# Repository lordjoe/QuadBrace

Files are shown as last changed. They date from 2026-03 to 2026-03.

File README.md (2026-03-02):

# QuadBrace — 3D-Printable Assistive Tool Holder for Quadriplegics

A set of parametric OpenSCAD models that together form a wrist-worn assistive device, allowing individuals with quadriplegia (tetraplegia) to independently pick up and use everyday tools such as forks, knives, and other utensils.

## Preview

| Wrist Brace | Main Box | Top Plate |
|:---:|:---:|:---:|
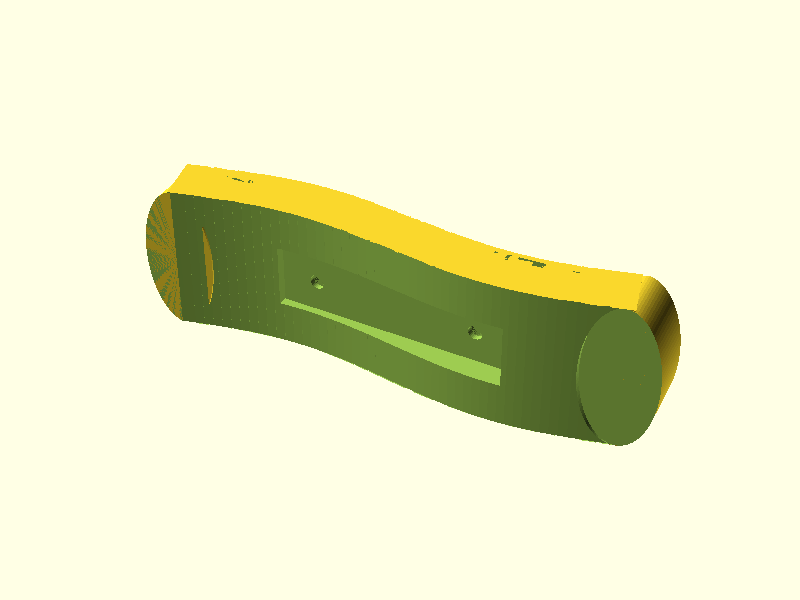
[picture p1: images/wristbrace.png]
Wrist Brace
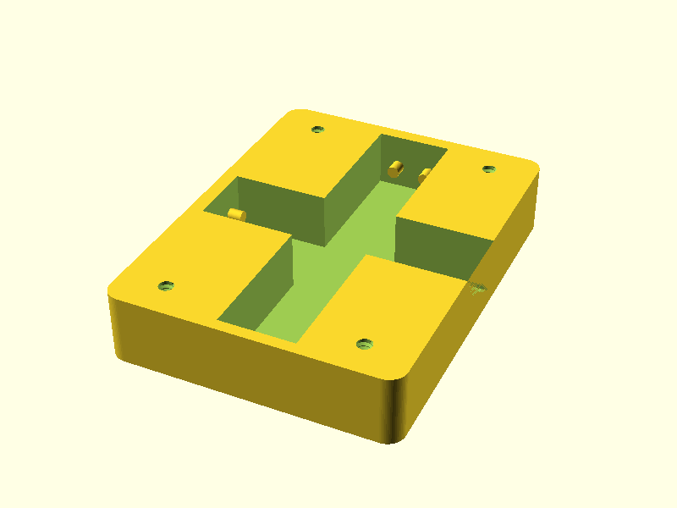
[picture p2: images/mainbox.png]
Main Box
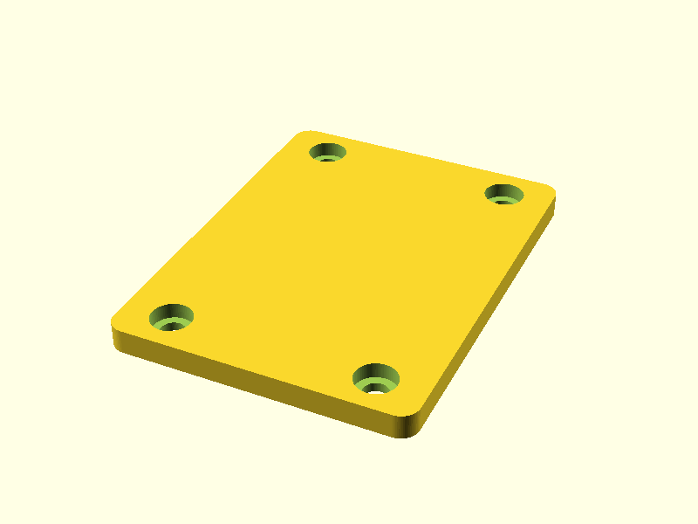
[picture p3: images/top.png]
Top Plate
|  |  |  |
| **Assembly — sliders and springs** — semi-transparent box; blue = Y-groove slider (wide end toward sealed wall), green = X-groove spring slider (at closed end), red/orange coils = springs from slider pegs to end-wall pegs |||
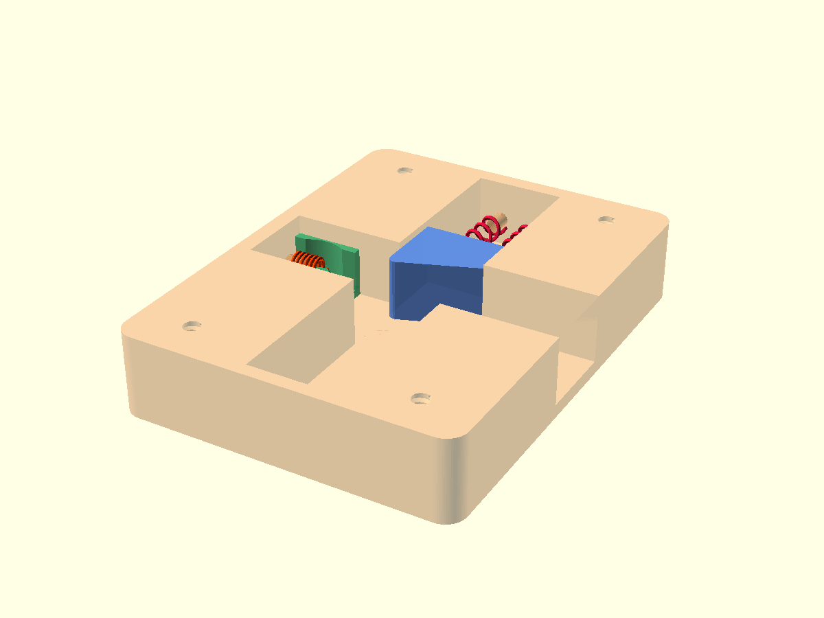
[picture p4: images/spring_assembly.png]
Spring assembly
|  |||

## Purpose

People living with quadriplegia often have limited or no hand/finger function, making it difficult or impossible to grip tools unaided. This device provides a spring-loaded, quick-release mounting system that attaches to the wrist and holds tools securely while allowing easy release — restoring a degree of independence for feeding and other daily tasks.

## How It Works

The assembly consists of four main functional layers:

1. **Wrist Brace** (`wristbrace.scad`) — A curved, sine-wave-contoured band that conforms to the wrist. Strap slots allow it to be secured with hook-and-loop (Velcro) straps. A rectangular cutout in the brace receives the Main Box.

2. **Main Box** (`MainBox.scad` + `Top.scad`) — A compact rectangular housing that mounts into the brace. It contains two orthogonal sliding grooves (one along the wrist, one across it) with spring pegs at each sealed end. A thin top plate caps the assembly.

3. **Slider / Pusher** (`Slider.scad`, `TopSpringSlider.scad`, `pusher2.scad`) — A slider block sits inside the groove and is held in place by spring pegs. Pressing a pusher lever releases the slider, which then carries the tool holder outward for easy access, then snaps back when released.

4. **Tool Holder** (`holder.scad`) — A cylindrical clamp that grips the shaft of a fork, knife, spoon, or similar tool. Slotted for quick swap of tools; tightened with a single screw. A matching **rest/cradle** (`fork_rest`) provides a surface to park the tool when the brace is removed.

## Files

| File | Description |
|---|---|
| `common_params.scad` | Shared dimensions and fit parameters for the Main Box assembly |
| `params_quadbrace.scad` | Shared parameters for the pusher, sleeve, slider, and wrist brace |
| `geom_helpers.scad` | Reusable geometry modules (rounded prisms, screw holes, spring pegs) |
| `MainBox.scad` | Main mounting box with cross-shaped grooves and spring pegs |
| `Top.scad` | Thin top plate with counterbored screw holes |
| `wristbrace.scad` | Sine-contoured wrist band with strap cutouts and box slot |
| `holder.scad` | Cylindrical tool clamp + flat rest/cradle |
| `pusher2.scad` | Pusher stem, shell sleeve, and end-cap release mechanism |
| `Slider.scad` | Slider block that travels in the Main Box grooves |
| `TopSpringSlider.scad` | Spring-loaded top slider variant |
| `pyramid.scad` | Pyramid/ramp geometry for slider leading edge |
| `key.scad` | Anti-rotation key geometry |
| `PrintAll.scad` | Print any combination of parts on one bed; set `print_all = true` or flip individual flags |
| `AssemblyPreview.scad` | Exploded assembly preview (all parts together) |

## Requirements

- [OpenSCAD](https://openscad.org/) 2021.01 or later
- [BOSL2 library](https://github.com/BelfrySCAD/BOSL2) — place the `BOSL2/` folder in your OpenSCAD library path

## Printing

All parts are designed for FDM printing (PLA or PETG recommended). No supports are required for most parts. Suggested settings:

- Layer height: 0.2 mm
- Infill: 30–40%
- Perimeters: 3+
- Hardware: M3 or #6/#8 machine screws (see parameter files for exact sizes)

## Customisation

All critical dimensions are centralised in `common_params.scad` and `params_quadbrace.scad`. Adjust wrist width, tool diameter, groove clearances, and peg sizes to match the user's anatomy and chosen hardware before slicing.

## License

Released under the [Creative Commons Attribution 4.0 International (CC BY 4.0)](https://creativecommons.org/licenses/by/4.0/) licence. You are free to print, modify, and share this design — attribution appreciated.

## Contributing

Pull requests and issue reports are welcome. If you adapt this design for a specific tool or user need, please share your fork so others can benefit.

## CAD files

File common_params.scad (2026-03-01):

include <BOSL2/std.scad>;
include <BOSL2/threading.scad>;
include <BOSL2/screws.scad>;
// common_params.scad
// Extracted (approx) from HolderAssembly.stl: MainBox = component 15, Top = component 8
// Units: mm. OpenSCAD 2021.01 compatible.

$fn = 72;
eps = 0.02;

// ---------- Overall footprint ----------
plate_x = 49.000;   // X size (short)
plate_y = 65.000;   // Y size (long)
corner_r = 3.0;
screw_inset = 10;  // insey of screws in main box from x edge

main_thick = 12.000;
top_thick  = 4.000;

// ---------- Fastener pattern ----------
hole_d = 4; // was 3.5;
hole_offset_x = 16.500;  // from center along X
hole_offset_y = 26.500;  // from center along Y

// Optional counterbore on Top
top_counterbore_enable = true;
top_counterbore_d = 6.6;
top_counterbore_depth = 2.5;

// ---------- MainBox grooves (from STL height-map) ----------
// Groove depth from top surface:
groove_depth = 10.000;

// Groove A: runs along Y (long direction). Width in X.
grooveY_enable = true;
grooveY_x_center = 1.082;
grooveY_x_width  = 13.000;
grooveY_y_start_stop = 2.000; // distance from -Y edge
grooveY_y_end_stop   = 2.500;   // distance from +Y edge

// Groove B: runs along X. Width in Y.
grooveX_enable = true;
grooveX_y_center = 0.0; //3.587;
grooveX_y_width  = 12.000;
grooveX_x_start_stop = 2.500; // distance from -X edge
grooveX_x_end_stop   = 0.000;   // distance from +X edge (0 => breaks out)

// ---------- Spring pins at grooveY end (you can tune) ----------

// ---------- End-wall pegs (spring pegs) ----------
// Pegs are on the END WALL of a slot, pointing INTO the slot along the slot axis.
pegs_enable = true;
peg_d   = 2.2;     // peg diameter
holder_ped_d = peg_d* 1.45;
peg_len = 2.5;     // how far peg protrudes into slot
peg_z_from_floor = 4.0;  // peg center height above groove floor
peg_count = 2;     // pegs per sealed end
peg_spacing = 6.0; // spacing across slot width (perpendicular to slot axis)
peg_edge_inset = 2.0; // inset from slot wall in the perpendicular direction (keeps pegs away from edges)

// ---------- Part 5 (slider block) ----------
// Dimensions extracted from original STL (component 0 / 5)
part5_stl_x = 13.000;   // across GrooveY width direction (X)
part5_stl_y = 11.544;   // along GrooveY travel direction (Y)
part5_stl_z = 9.000;   // height (Z)

// Fit tuning
part5_clearance_x = 0.25;  // per-side clearance in X vs groove
part5_clearance_y = 0.25;  // per-side clearance in Y vs groove walls/end pegs clearance
part5_clearance_z = 0.25;  // per-side clearance in Z vs groove depth

// Pegs on Part5: match MainBox pegs exactly
part5_pegs_enable = true;
part5_peg_end = "AUTO"; // "AUTO","PLUS_Y","MINUS_Y","BOTH" (AUTO picks sealed end)

// Part5 slant (leading ramp) - matches earlier prism-with-slant versions
part5_slant_enable = true;
part5_slant_end = "OPEN_END";   // "OPEN_END" or "SEALED_END"
part5_slant_len = 4.0;          // length of slanted region along Y
part5_slant_drop = 3.0;         // how much height is removed at the very end (Z)

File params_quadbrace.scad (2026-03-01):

// params_quadbrace.scad
// Shared parameters for pusher/sleeve(part2)/slider(part5)/pyramids/wristbrace demos
// Units: mm. OpenSCAD 2021.01 compatible.

$fn = 64;
eps = 0.02;

// --- Part 9 / pusher ---
stem_len = 35;
stem_w   = 11;
stem_h   = 9;

stem_ext_len = 10;
stem_ext_w   = 7;
stem_ext_h   = 5;

head_attach_scale = 0.75;

// "header" outer block style (solid, no hole)
sleeve_t = 4.9;
sleeve_w = 12;
sleeve_h = 10;
sleeve_r = 1.0;

// --- Sleeve hole sizing (Part 2 slider-with-hole) ---
fit_clearance = 0.7;
head_w = 7;
head_h = 5;

hole_w_y = head_w + 2*fit_clearance;
hole_h_z = head_h + 2*fit_clearance;
hole_r   = 0.8;

// --- Part 5 slider (faceted) ---
slider_len_x = 13.0;
slider_w_y   = 11.54376125;
slider_h_z   = 9.0;
xy_clearance = 0.0;

enable_pegs  = true;
peg_d        = 2.2;
peg_len_y    = 2.5;
peg_z_center = 0.5;
peg_x_spacing = slider_len_x/2;
peg_on_max_y  = true;

// --- Pyramid defaults ---
pyr_height_x = 4.91014528;
pyr_width_y  = 12.0;
pyr_depth_z  = 10.0;
pyr_slope_deg = 45;

// --- Wristbrace sine sweep demo ---
sine_length = 120;
sine_amplitude = 15;
sine_wavelength = 40;
sine_steps = 80;
sweep_cube_size = [4,4,4];

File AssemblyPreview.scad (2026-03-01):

// AssemblyPreview.scad
include <common_params.scad>;
include <geom_helpers.scad>;
include <MainBox.scad>;
include <Top.scad>;
include <Part5.scad>;

explode_z = 2.0;

translate([0,0,0]) MainBox();
translate([0,0,main_thick + explode_z]) Top();

// Optional Part5 preview positioned roughly over Groove A
show_part5 = true;
if (show_part5) {
    // Place on top surface near center; adjust as needed
    translate([0, 0, main_thick + explode_z + top_thick + 0.5])
        Part5();
}

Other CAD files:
geom_helpers.scad
MainBox.scad
PrintAll.scad
Slider.scad
SpringAssembly.scad
Top.scad
TopSpringSlider.scad
holder.scad
key.scad
pusher2.scad
pyramid.scad
wristbrace.scad

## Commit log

2026-03-01 Initial release of QuadBrace assistive tool-holder for quadriplegics
    Parametric OpenSCAD models for a 3D-printable wrist-worn device that
    lets quadriplegic users independently pick up and use everyday tools.
    [AssemblyPreview.scad, MainBox.scad, Slider.scad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]
2026-03-01 Add PrintAll.scad — single-file print-all with per-part selection
    Imports every printable file via `use<>` so top-level renders don't
    fire, wraps each part in a module that places it flat on the bed at
    a positive-XY origin, then arranges all parts in three non-overlapping
    rows with a configurable gap. Set print_all=true for a full bed, or
    set print_all=false and flip individual flags for a subset.
    [PrintAll.scad]
2026-03-01 Drop key and pyramid from PrintAll — neither used by any other file
    [PrintAll.scad]
2026-03-01 Add PrintAll.scad to README file table
2026-03-02 Add SpringAssembly.scad with coil-spring assembly view
    Shows Y-groove slider (wide end toward sealed wall), X-groove TopSpringSlider
    at the closed end, and both pairs of coil springs connecting slider pegs to
    end-wall pegs. MainBox rendered semi-transparent so groove contents are visible.
    Image added to README preview section.
    [SpringAssembly.scad]
2026-03-02 Move assembly image into Preview table as a spanning second row
